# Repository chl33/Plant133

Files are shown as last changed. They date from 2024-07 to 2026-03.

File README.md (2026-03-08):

# Plant133

This is a full distribution of the Plant133 plant-watering device. This device can monitor and water up to 4 plants at a time. This repository hosts the firmware, PCBA design, and OpenSCAD code for all components.

A writeup about this project is at "[Plant1337: "Water 4 plants](https://selectiveappeal.org/posts/plant1337/)."

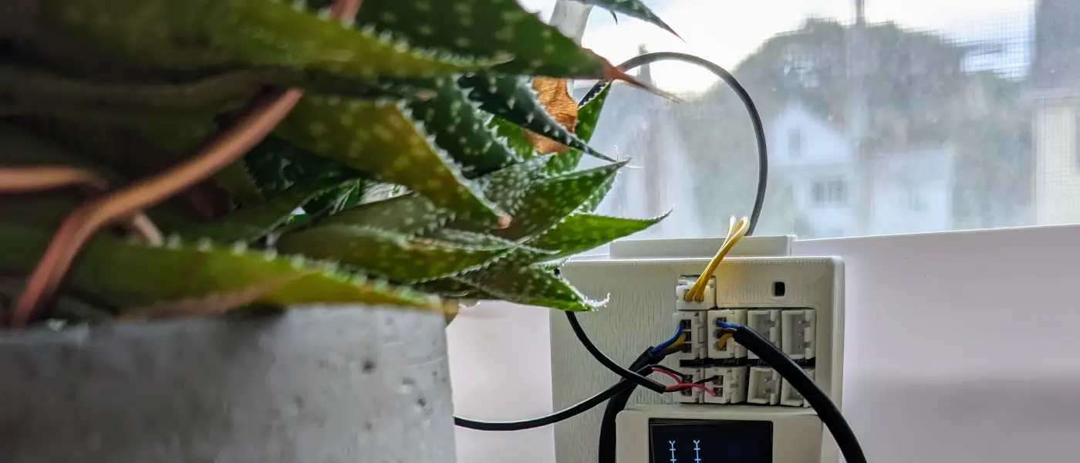
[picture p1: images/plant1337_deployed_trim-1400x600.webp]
Plant133 device


## Features

*   **Multi-Plant Support**: Monitors and independently waters up to 4 plants.
*   **Sensors**:
    *   Capacitive soil moisture sensing for each plant.
    *   SHTC3 temperature and humidity sensor for environmental monitoring.
    *   Reservoir water level float switch detection.
*   **User Interface**:
    *   **OLED Screen**: Rotates through status screens showing IP address, moisture levels, and environment data.
    *   **Web Dashboard**: A modern Svelte-based responsive web interface for real-time monitoring and configuration.
*   **Integration**:
    *   **MQTT**: Full support for Home Assistant auto-discovery and state reporting.
*   **Safety**:
    *   **Watchdog Timer**: Hardware watchdog protects against system hangs.
    *   **Dose Limiting**: Prevents over-watering by limiting the maximum number of pump cycles per day.
    *   **Reservoir Check**: Prevents pump damage by detecting low water levels.

## Usage

Please see the [instructions](instructions.md) for how to assemble and set up a Plant133 device hardware.

## Development

### Prerequisites
*   [PlatformIO](https://platformio.org/) (Core or VSCode extension)
*   [Node.js](https://nodejs.org/) (for building the web interface)

### Building and Flashing Firmware

1.  **Configure Secrets**: Copy `secrets.ini.example` to `secrets.ini` and set your WiFi credentials, OTA password, and MQTT details.
2.  **Onetime setup for building the web interface**:
    ```bash
	cd svelte
	npm install
	```
3.  **Build the Web interface and Firmware**:
    ```bash
    # For a specific board (e.g. usb_cactus)
    pio run -e usb_cactus
    ```
4.  **Upload Firmware**:
    ```bash
    pio run -e usb_cactus -t upload
    ```

## API Reference

The device exposes a JSON API for integration and control:

*   `GET /api/status`: Returns system status (temp, humidity, water level, MQTT connection).
*   `GET /api/plants`: Returns configuration for all plants.
*   `GET /api/moisture`: Returns current moisture readings and watering states.
*   `PUT /api/plants/{id}`: Update configuration for a specific plant.
*   `GET /api/wifi`: Get current WiFi SSID and board name.
*   `GET /api/mqtt`: Get MQTT configuration status.
*   `POST /test/pump`: Run a pump for a specific duration (JSON body: `{ "pumpId": 1, "duration": 1000 }`).
*   `POST /api/restart`: Restart the device.

## Software Libraries

This project is built using a custom C++ framework for ESP devices:
- [og3](https://github.com/chl33/og3): Application framework.
- [og3x-oled](https://github.com/chl33/og3x-oled): OLED screen support.
- [og3x-shtc3](https://github.com/chl33/og3x-shtc3): SHTC3 sensor support.
- [svelteesp32](https://github.com/BCsabaEngine/svelteesp32): Web interface integration.

## Hardware

### PCBA

The full [KiCAD](https://www.kicad.org/) project for the printed circuit board is in the [KiCAD](KiCAD/) subdirectory.

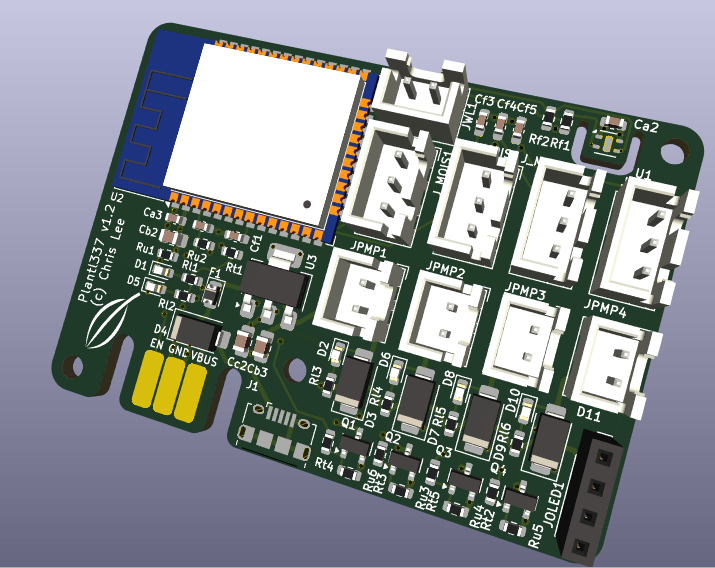
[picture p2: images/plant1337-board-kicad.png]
Plant1337 PCBA rendered by KiCAD


### 3D Printed Components

Components are designed in [OpenSCAD](https://openscad.org/). Source code is in the [scad](scad/) subdirectory.

#### Project box
Housing for the PCBA ([scad/box/](scad/box/)).
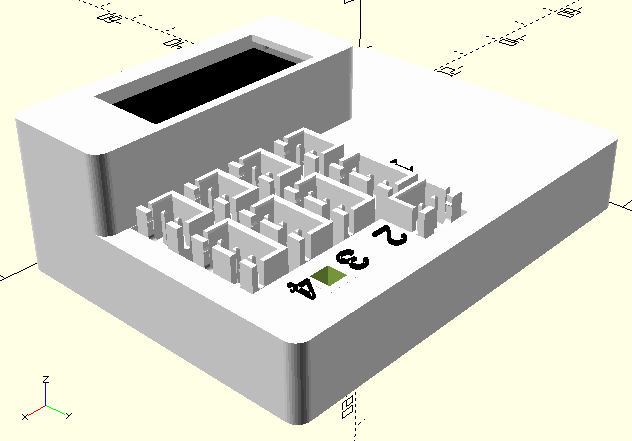
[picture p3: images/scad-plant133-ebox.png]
EBox design in OpenSCAD


#### Reservoir Hanger
Mounts the box to a water reservoir ([scad/ebox_hook](scad/ebox_hook)).
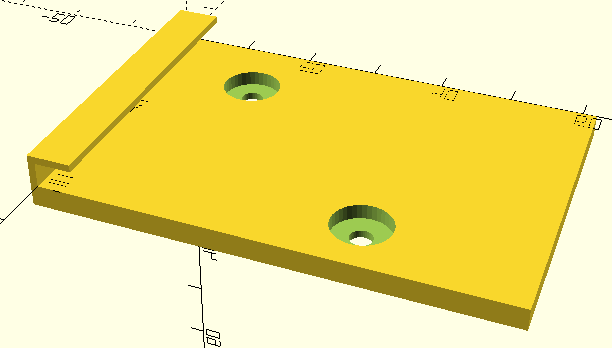
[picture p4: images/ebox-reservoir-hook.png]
Reservoir hanger


#### Reservoir Insert
Holds pumps and water level float ([scad/reservoir_insert](scad/reservoir_insert)).
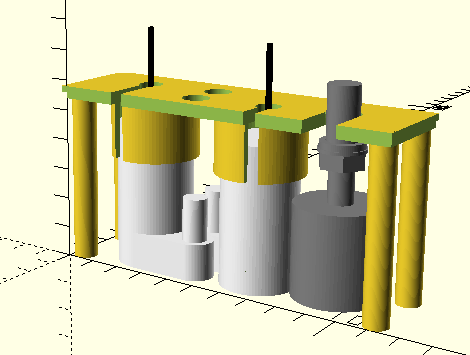
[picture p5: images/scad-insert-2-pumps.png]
Reservoir insert with 2 pumps


#### Moisture Sensor Cap
Holds the watering tube at the sensor location ([scad/moisture_sensor_cap](scad/moisture_sensor_cap)).
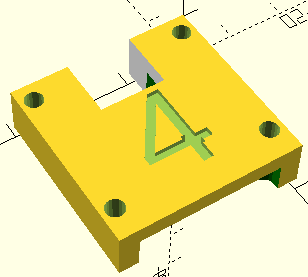
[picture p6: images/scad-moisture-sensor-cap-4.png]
Moisture sensor cap top


#### Watering Spike
Alternative watering method using a soil spike ([scad/spike](scad/spike)).
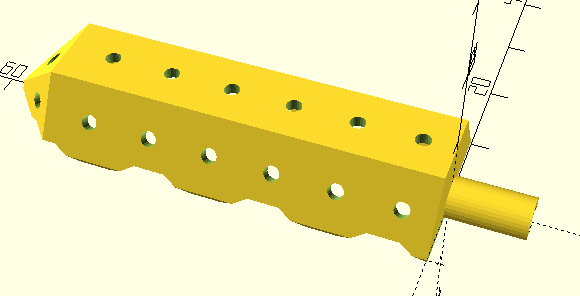
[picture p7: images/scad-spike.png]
Watering spike half


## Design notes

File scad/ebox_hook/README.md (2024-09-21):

This is a plate you can screw the EBox bottom onto, which then allows you to hang the EBox on the side of a water reservoir.

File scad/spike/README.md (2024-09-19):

This is an OpenSCAD model for a watering spike.  It is printed in 2 pieces which can be
glued together with Epoxy.

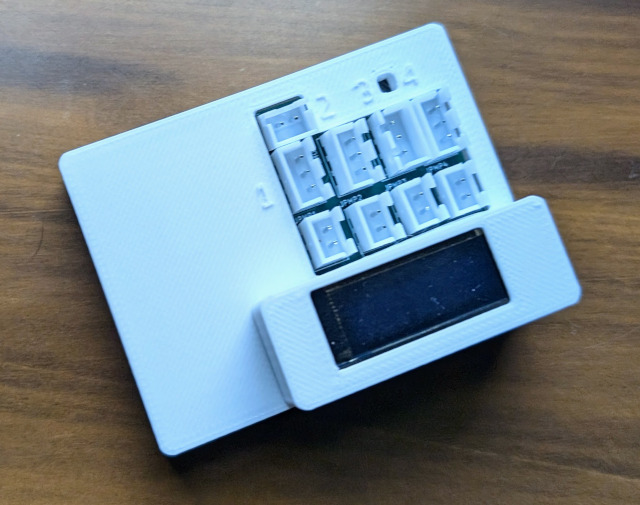
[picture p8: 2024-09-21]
images/plant1337-box.jpg

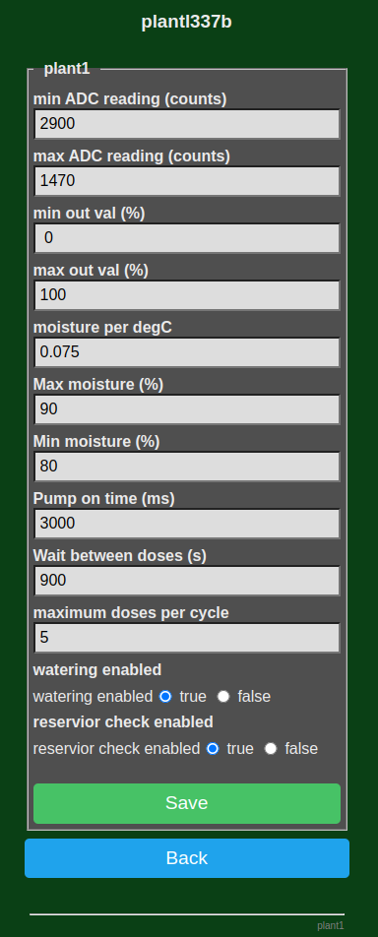
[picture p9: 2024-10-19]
images/web-water-config.png

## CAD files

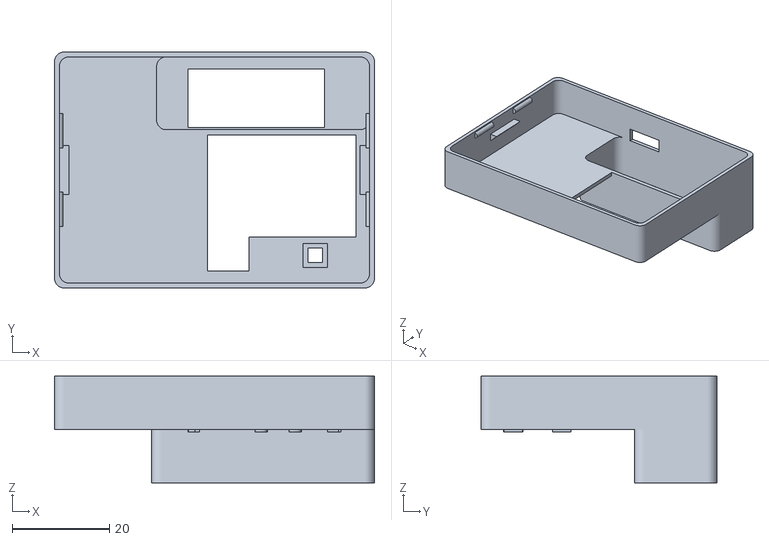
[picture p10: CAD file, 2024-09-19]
scad/box/box_top.stl
65.8 x 48.6 x 22.0

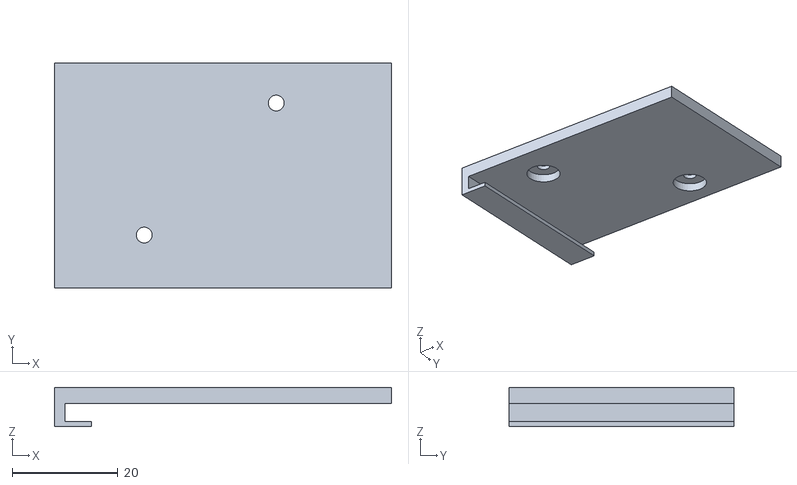
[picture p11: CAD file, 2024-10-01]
scad/ebox_hook/print_hook.stl
63.8 x 42.6 x 7.40

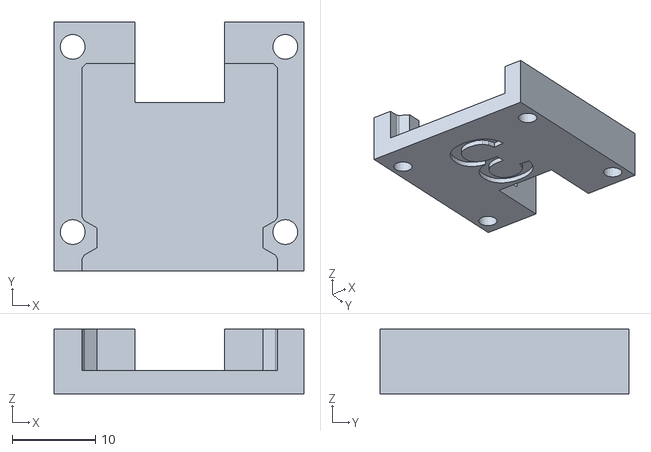
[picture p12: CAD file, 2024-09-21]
scad/moisture_sensor_cap/box_top_3.stl
30.1 x 30.0 x 7.79

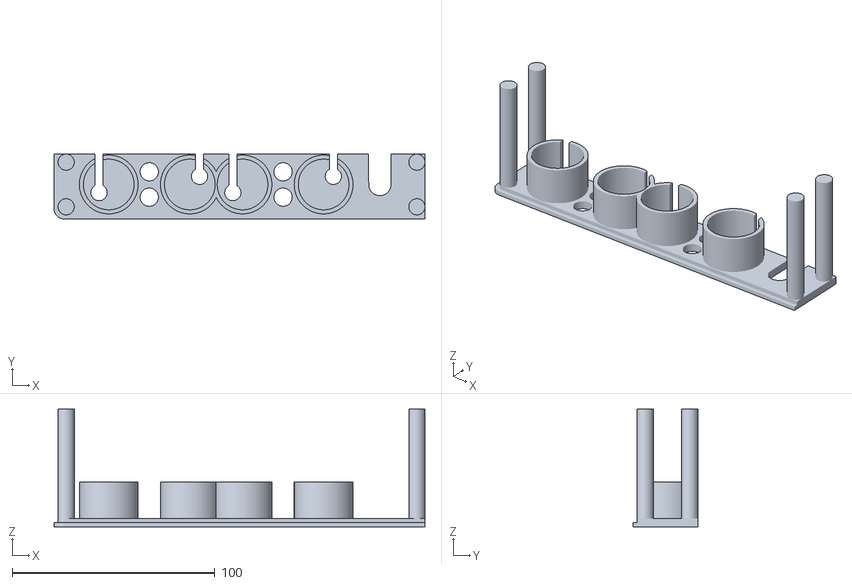
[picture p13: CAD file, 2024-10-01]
scad/reservoir_insert/insert_print.stl
183.0 x 32.0 x 58.0

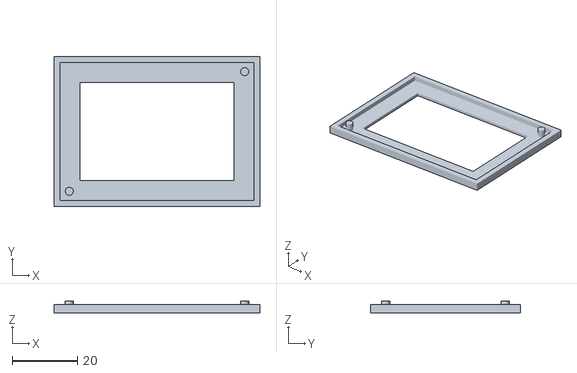
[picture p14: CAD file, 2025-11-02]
scad/stencil_fixture/stencil_fixture.stl
63.3 x 46.2 x 3.59

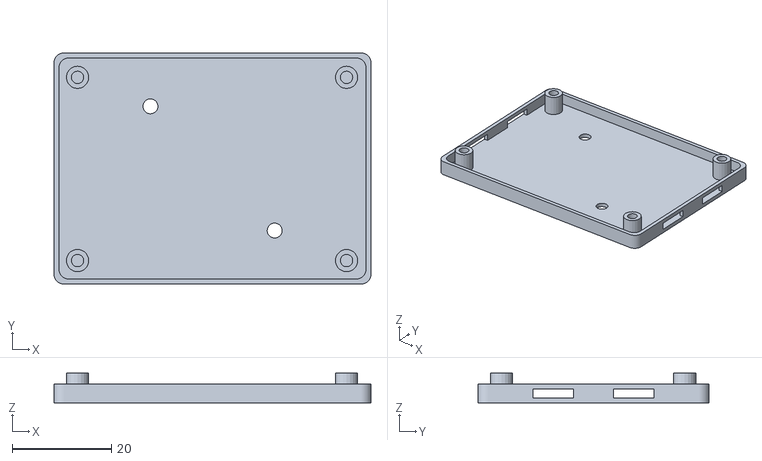
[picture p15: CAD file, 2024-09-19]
scad/box/box_bottom.stl
63.8 x 46.5 x 6.00

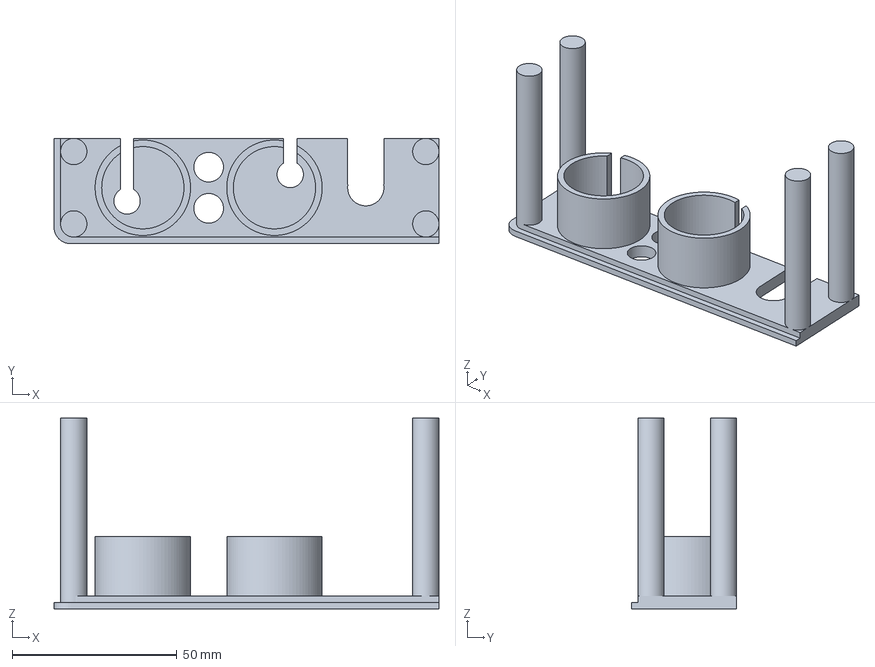
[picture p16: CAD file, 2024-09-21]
scad/reservoir_insert/reservoir_insert.3mf
117.0 x 32.0 x 58.0 mm

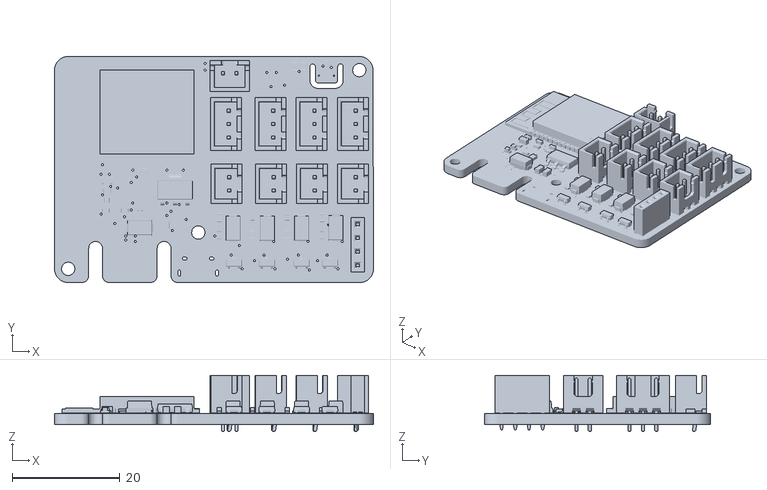
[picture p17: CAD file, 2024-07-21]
scad/box/Plant1337.stl
59.1 x 41.9 x 10.4

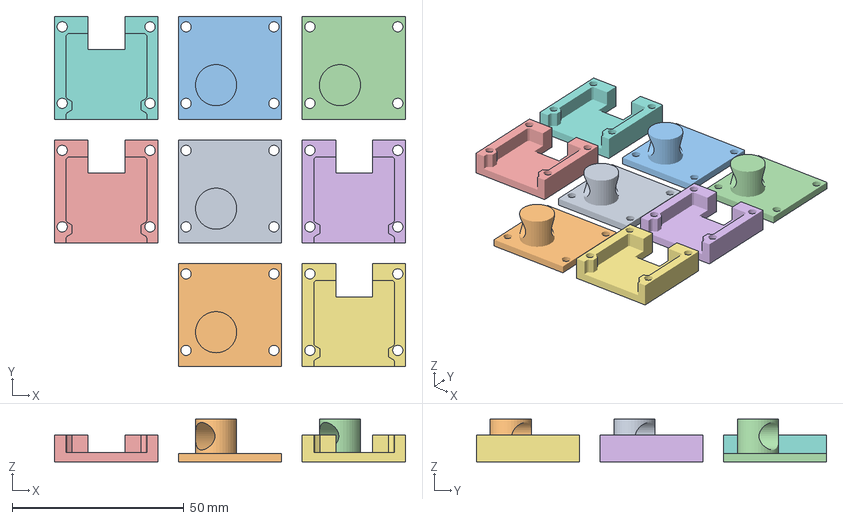
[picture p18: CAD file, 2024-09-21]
scad/moisture_sensor_cap/moisture_caps.3mf
102.3 x 102.0 x 12.5 mm
box_bottom.stl
box_top_4.stl
box_top_3.stl
box_top_2.stl
box_top_1.stl

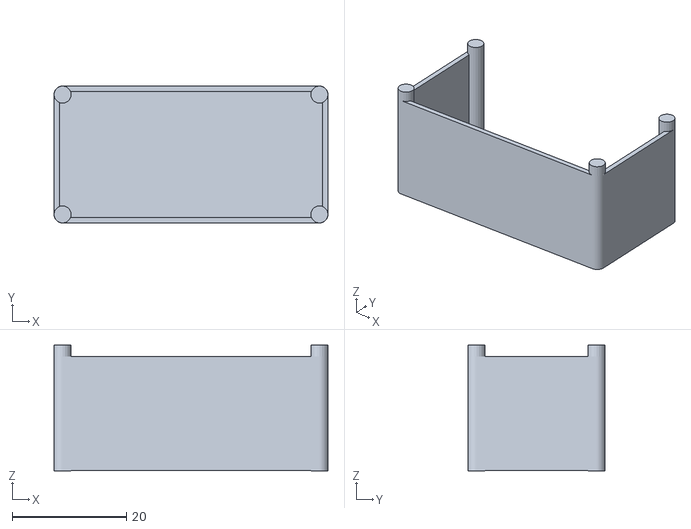
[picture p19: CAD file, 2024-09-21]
scad/reservoir_insert/insert_top_print.stl
48.0 x 24.0 x 22.0

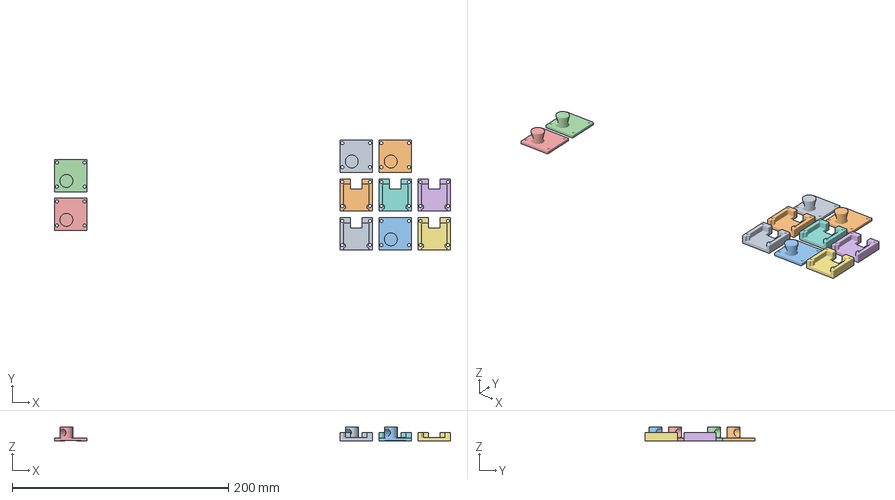
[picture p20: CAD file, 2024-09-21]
scad/moisture_sensor_cap/moisture_cap.3mf
366.2 x 102.0 x 12.5 mm
box_bottom.stl
box_top.stl

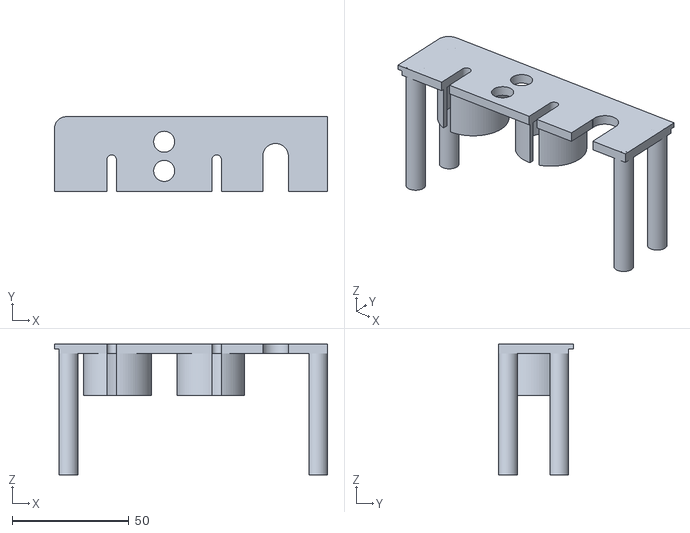
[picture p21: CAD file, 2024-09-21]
scad/reservoir_insert/insert.stl
117.0 x 32.0 x 56.0

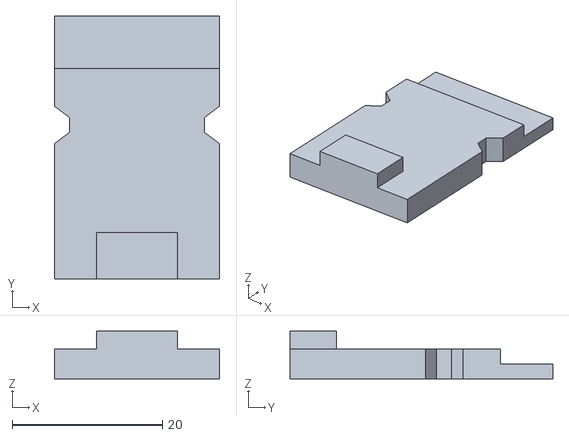
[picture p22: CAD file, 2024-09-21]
scad/moisture_sensor_cap/sensor_test.stl
22.0 x 35.0 x 6.38

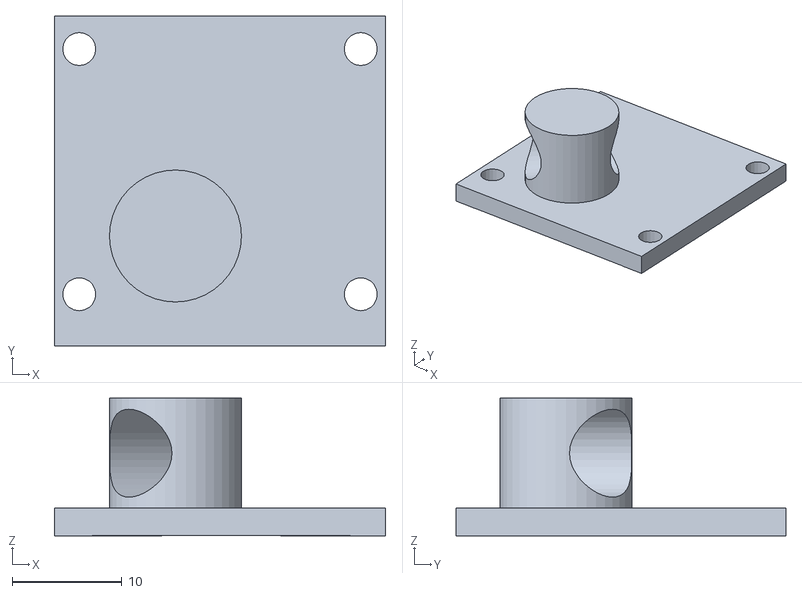
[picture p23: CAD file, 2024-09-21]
scad/moisture_sensor_cap/box_bottom.stl
30.1 x 30.0 x 12.5

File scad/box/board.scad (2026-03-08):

// Copyright (c) 2026 Chris Lee and contributors.
// Licensed under the MIT license. See LICENSE file in the project root for details.

include <ProjectBox/project_box.scad>

board_thickness = 1.6;
pad_space = 2.54;
board_dims = [23.4*pad_space, 16.6*pad_space, board_thickness];

module Plant1337_to_oled_frame() {
  u = pad_space;
  translate([u*23-0.5, 0.6, 13]) rotate([0, 0, 90]) children();
}

module oled() {
  s = inch * 0.1;
  pin_len = 4;
  color("silver") {
    for (i = [0: 3]) {
      translate([s*i+pad_space, pad_space/2, -pin_len]) cube([0.25, 0.25, pin_len]);
    }
  }
  color("gray") cube([12, 38, 1]);
  translate([0, 5.5, 1]) color("black") cube([12, 28, 1]);
}

module Plant1337_board() {
  u = pad_space;

  // Board imported from KiCad (VRML) -> meshlab
  translate([board_dims[0]/2, board_dims[1]/2, board_dims[2]/2]) color("white")
    import(file="Plant1337.stl", convexity=3);

  Plant1337_to_oled_frame() oled();
}

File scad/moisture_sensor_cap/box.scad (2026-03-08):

// Copyright (c) 2026 Chris Lee and contributors.
// Licensed under the MIT license. See LICENSE file in the project root for details.

include <moisture_sensor.scad>

sensor_num = "4";
wall_thickness = 3;

grow_offset = 0.8;

grown_moisture_sensor_dims = moisture_sensor_dims + [2, 1, 1] * grow_offset;
moisture_box_dims = [grown_moisture_sensor_dims[0] + 2 * wall_thickness,
		     30,
		     2*wall_thickness+grown_moisture_sensor_dims[2]+2];

sensor_offset = [(moisture_box_dims[0] - grown_moisture_sensor_dims[0])/2+grow_offset/2,
		 wall_thickness+2,
		 wall_thickness];

module tube_holder() {
  $fn = 40;
  difference() {
    cylinder(10, 6, 6);
    translate([0, 0, 5]) rotate(45, Z) rotate(90, X) translate([0, 0, -7]) cylinder(14, 4, 4);
  }
}

module moisure_sensor_cap(top) {
  wall = wall_thickness;
  dims = moisture_box_dims;
  difference() {
    union() {
      cube(dims);
      translate([11, 20, -10+epsilon]) tube_holder();
    }
    
    translate(sensor_offset) moisture_sensor(true);
    cut_height = 2.51;
    if (top) {
      translate([-1, -1, -20]) cube([3+dims[0], 3+dims[1], cut_height+20]);
      text_size = 15;
      text_depth = 0.8;
      translate([20.5, 25, dims[2]-text_depth+epsilon])
	linear_extrude(2*text_depth) {
	rotate(180, Z) text(sensor_num, size=text_size);
      }
    } else {
      translate([-1, -1, cut_height + epsilon]) cube([3+dims[0], 3+dims[1], 30]);
    }
    // Screw holes
    translate([0, 5.5, 0]) {
      translate([2.25, 19.8, -1]) cylinder(dims[2]+2, 3/2, 3/2, $fn=20);
      translate([dims[0]-2.25, 19.8, -1]) cylinder(dims[2]+2, 3/2, 3/2, $fn=20);
    }
    // Screw holes
    translate([0, -16.5, 0]) {
      translate([2.25, 19.5, -1]) cylinder(dims[2]+2, 3/2, 3/2, $fn=20);
      translate([dims[0]-2.25, 19.5, -1]) cylinder(dims[2]+2, 3/2, 3/2, $fn=20);
    }
  }
}

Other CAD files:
scad/moisture_sensor_cap/box_top_1.stl
scad/moisture_sensor_cap/box_top_4.stl
scad/moisture_sensor_cap/box_top_2.stl
scad/moisture_sensor_cap/box_bottom.scad
scad/moisture_sensor_cap/box_top.scad
scad/box/Plant1337_test.scad
scad/box/box.scad
scad/box/box_bottom.scad
scad/box/box_top.scad
scad/box/gui.scad
scad/ebox_hook/hook.scad
scad/ebox_hook/print_hook.scad
scad/moisture_sensor_cap/moisture_sensor.scad
scad/moisture_sensor_cap/sensor_test.scad
scad/moisture_sensor_cap/test.scad
scad/reservoir_insert/gui.scad
scad/reservoir_insert/insert_print.scad
scad/reservoir_insert/insert_test.scad
scad/reservoir_insert/insert_top_print.scad
scad/reservoir_insert/reservoir_insert.scad
scad/reservoir_insert/reservoir_insert.stl
scad/spike/spike.scad
scad/stencil_fixture/stencil_fixture.scad

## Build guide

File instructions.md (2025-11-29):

# Plant133 Setup Instructions

Follow this guide to assemble and configure your Plant133 watering system.

## 1. Hardware Assembly

### Mounting the Control Box
Hang the EBox on the side of your water reservoir. Place your plant and reservoir in their final location, ensuring access to a USB power source.

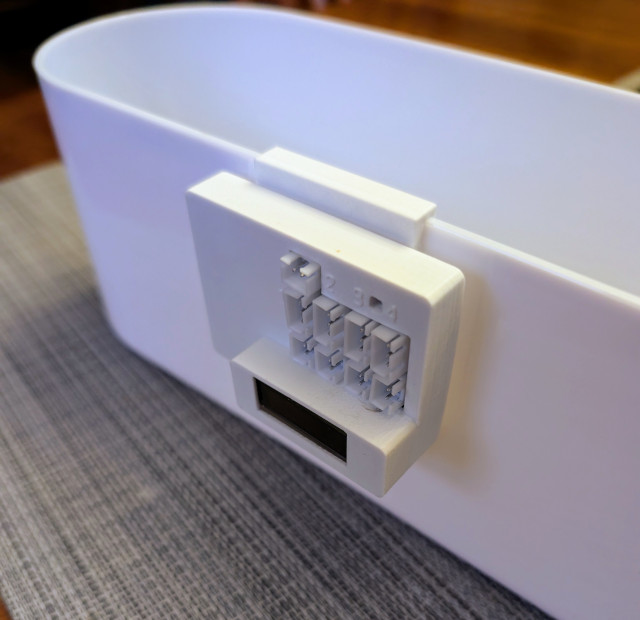
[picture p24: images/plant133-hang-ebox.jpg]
Hang EBox


### Reservoir Setup

1.  **Install the Water Level Float**:
    Place the float into the reservoir insert.
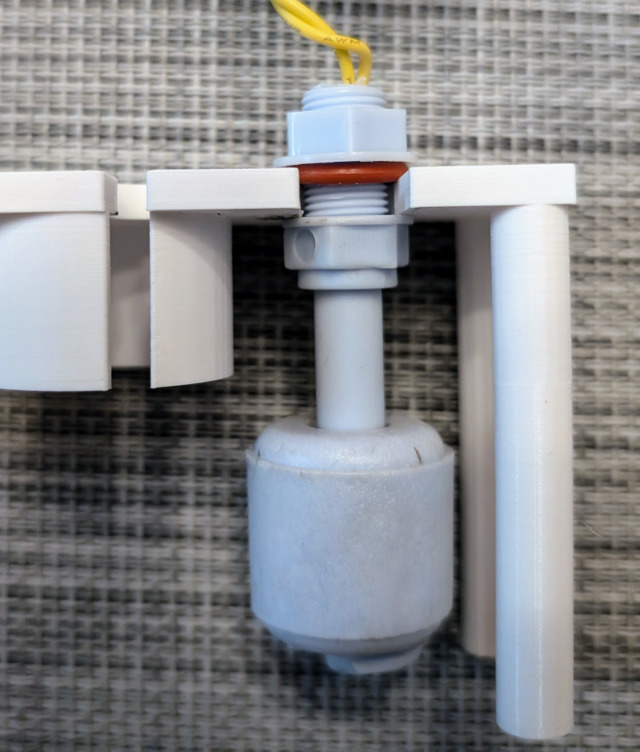
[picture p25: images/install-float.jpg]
Install Float
    

    Wire the float to the EBox.
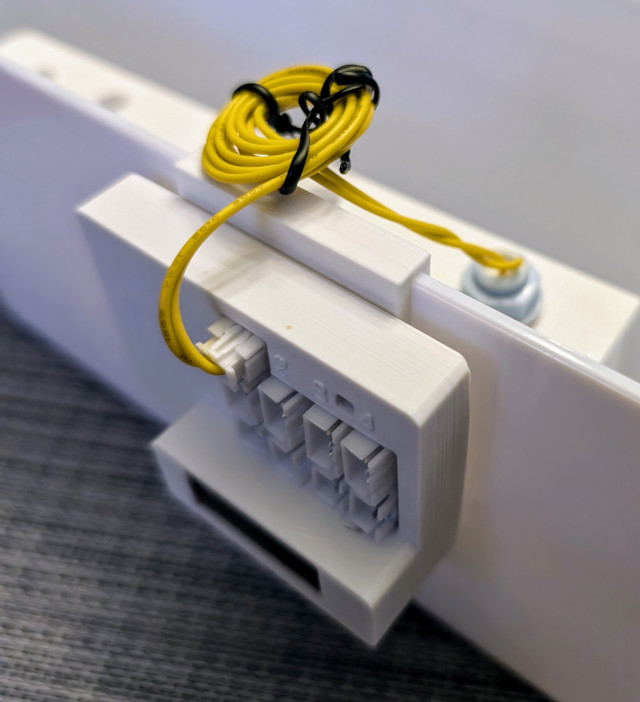
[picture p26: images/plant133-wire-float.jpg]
Wire Float
    

2.  **Install the Pump**:
    For each plant you intend to water, place a pump into the reservoir insert.
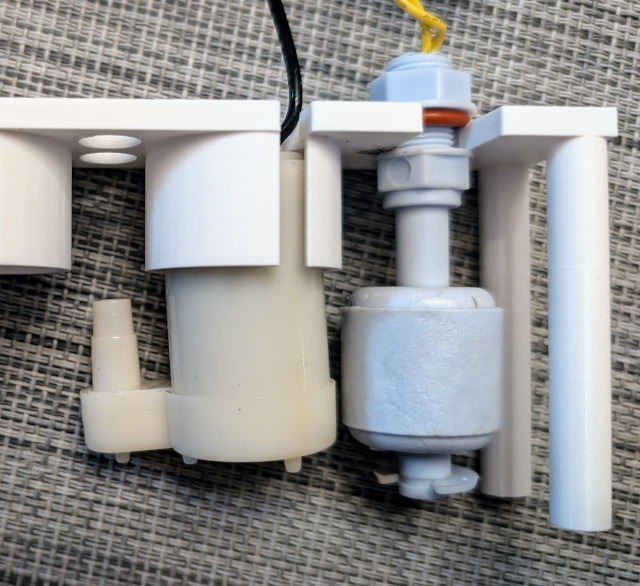
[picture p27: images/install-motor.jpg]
Install Motor
    

### Wiring and Tubing

For each plant,

3.  **Connect Sensors and Pumps**:
    Connect the soil moisture sensor and the corresponding pump to the EBox. Ensure connectors are aligned vertically under the same number (1-4).
    *   The soil moisture sensor uses a 3-conductor wire with JST connectors.
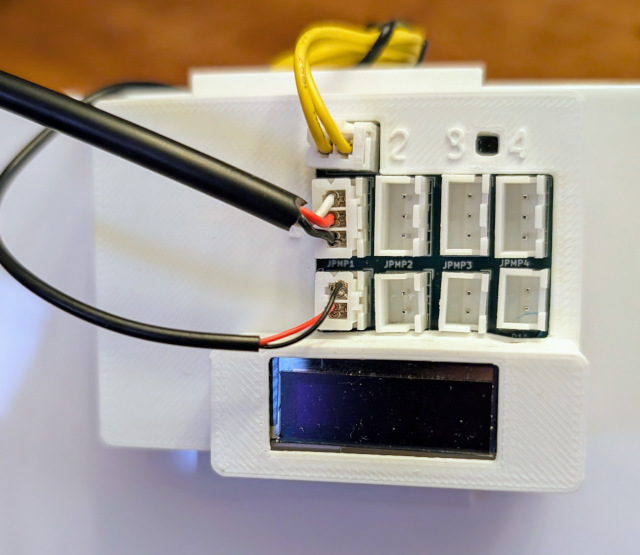
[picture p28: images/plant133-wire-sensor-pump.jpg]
Wire Sensor and Pump
    

4.  **Run Tubing**:
    Run a tube from the pump, through the hole in the insert, towards the plant pot.
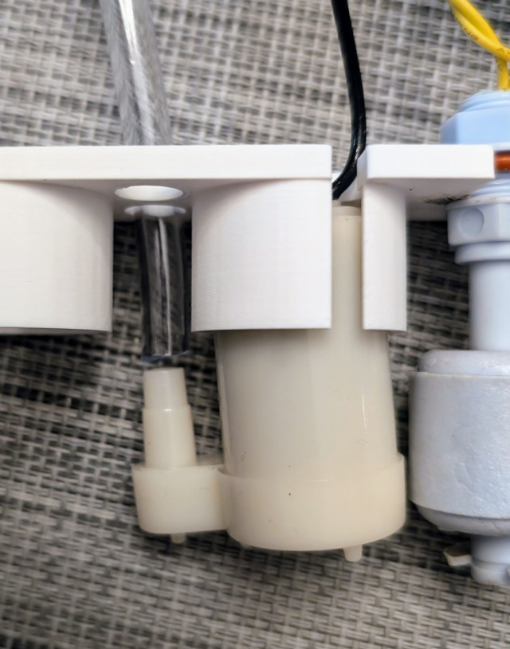
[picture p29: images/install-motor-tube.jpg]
Install Motor Tube
    

5.  **Position Water Outlet**:
    Cut the tube to the appropriate length and choose one of the following methods:
    *   **Method A (Cap)**: Push the tube end through the hole in the moisture sensor cap.
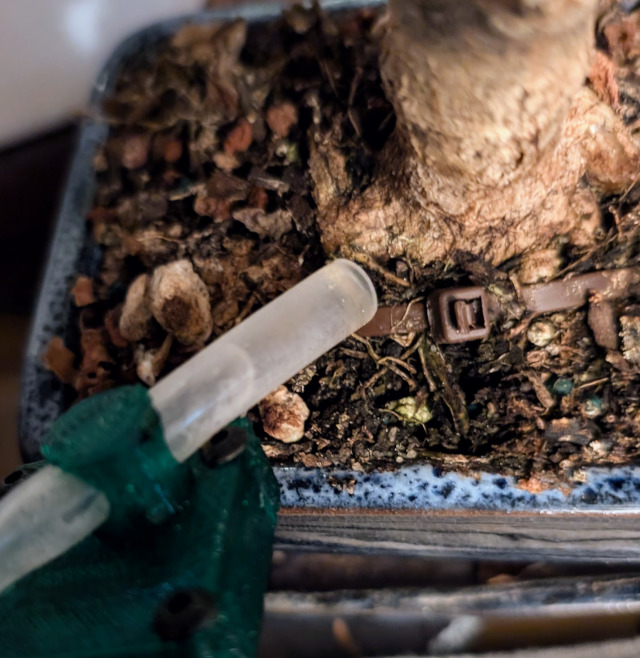
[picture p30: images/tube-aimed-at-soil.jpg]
Tube Aimed at Soil
        
    *   **Method B (Spike)**: Insert the tube into a 3D-printed soil spike and insert the spike into the soil.
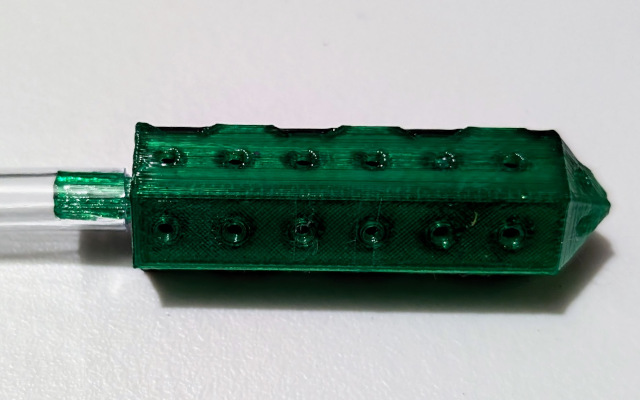
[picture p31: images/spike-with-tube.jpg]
Spike with Tube
        
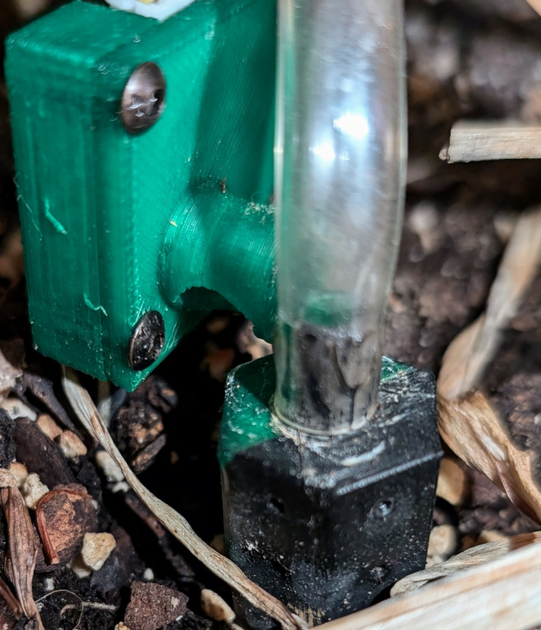
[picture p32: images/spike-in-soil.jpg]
Spike in Soil
        

6.  **Power Up**:
    Connect the EBox to power using a Micro-USB cable.

## 2. Network Configuration

1.  **Connect to Device AP**:
    Look for a WiFi network named `plant133` (or similar) on your phone or computer. Connect to it.
    *   *Note: The AP password (if set) and specific ESSID may be displayed on the device's OLED screen.*

2.  **Access Configuration Page**:
    Open a web browser and navigate to `http://192.168.4.1`. You may need to accept a warning about a non-encrypted connection.

3.  **Configure WiFi**:
    *   Click **"WiFi Setup"** on the main page.
    *   Enter your home WiFi credentials.
    *   Click **"Save"**, then **"Back"**, and finally **"Restart"** to reboot the device.
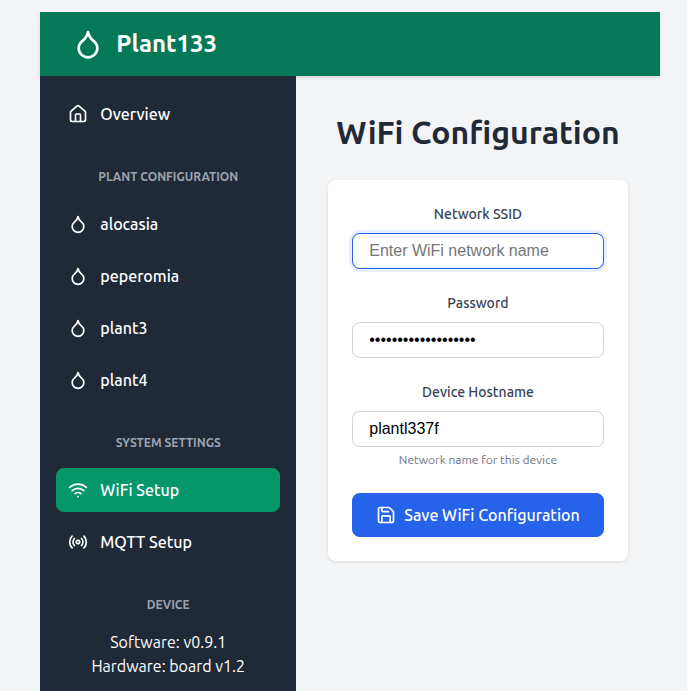
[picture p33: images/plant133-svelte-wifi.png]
Web WiFi Config
    

4.  **Reconnect**:
    Connect your phone/computer back to your home WiFi network. Look at the device's OLED screen to find its new IP address (e.g., `192.168.1.x`) or try accessing `http://plant133.local` (if mDNS is active).

## 3. Device Configuration

### MQTT Setup (Optional)
If you use Home Assistant or another home automation system:
1.  Navigate to the **MQTT Setup** page via the web interface.
2.  Enter your Broker address, port, and credentials.
3.  Save. The device should automatically appear in Home Assistant if discovery is enabled.
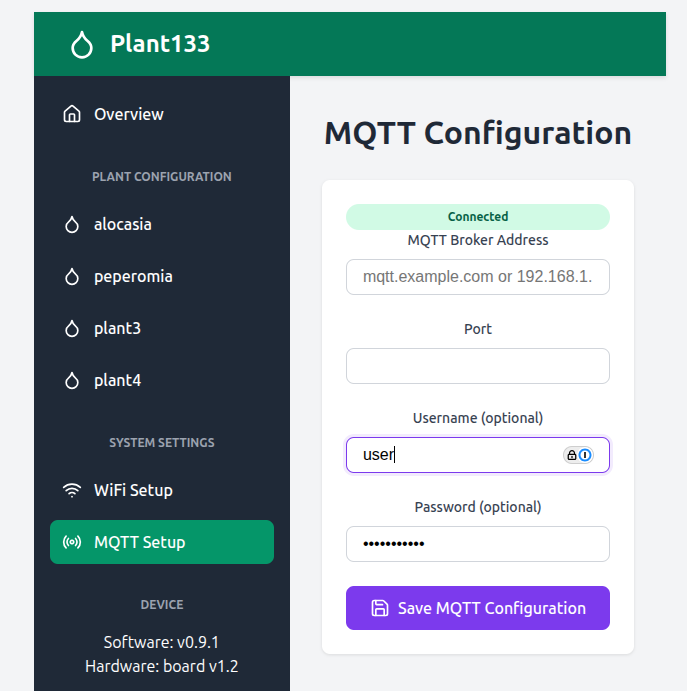
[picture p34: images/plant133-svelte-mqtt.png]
Web MQTT Config
    

### Plant Configuration
Select a plant from the main menu and click the settings icon.

*   **Moisture Targets**: Set the **Minimum** (start watering) and **Maximum** (stop watering) soil moisture percentages.
*   **Dose Duration**: Set how long the pump runs per dose (in milliseconds).
    *   *Recommendation:* Start with 1000ms (1s) for small pots, 3000ms (3s) for medium pots.
*   **Calibration**:
    *   **Wet (100%)**: Submerge the sensor (excluding the electronic cap) in a glass of water. Note the "Raw Moisture" ADC value and enter it as `ADC Counts at 100%`.
    *   **Dry (0%)**: Dry the sensor completely. Enter the reading as `ADC Counts at 0%`.
    *   *Note: Lower ADC values usually mean higher moisture (more conductivity).*
*   **Dosing Logic**:
    *   **Seconds between doses**: Time to wait for water to soak in before checking moisture again (Default: 900s / 15 min).
    *   **Max doses per cycle**: Safety limit to prevent flooding if the sensor fails (Default: 5).
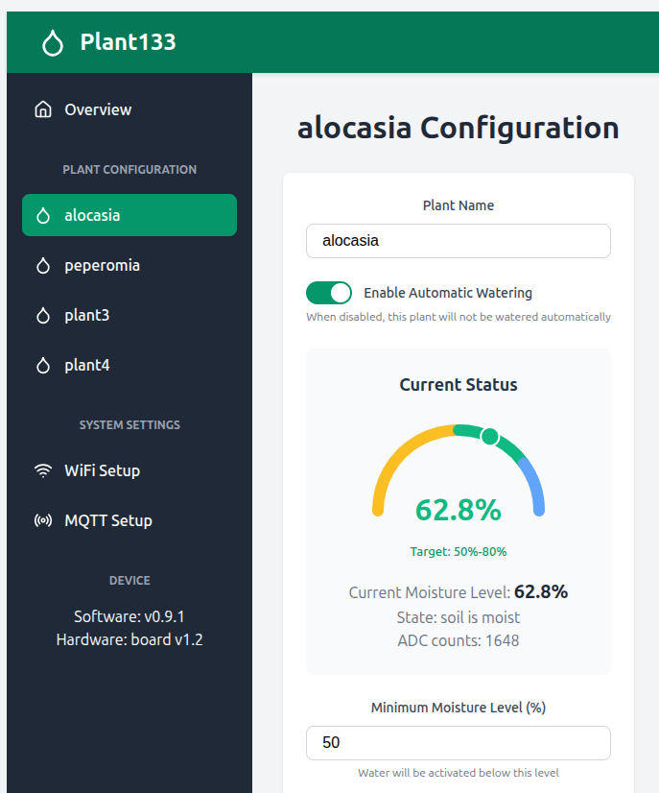
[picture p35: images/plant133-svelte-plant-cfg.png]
Web Watering Config
    

## 4. Final Steps

1.  **Enable System**: In the configuration page, toggle **"Enable Automatic Watering"**.
2.  **Fill Reservoir**: Add water to your reservoir.
3.  **Monitor**: Watch the system for the first few cycles and adjust `Pump On Time` or moisture thresholds as needed.

### Advanced
*   **Grafana**: Set up a dashboard to visualize moisture trends over time.
*   **Home Assistant**: Create automations to alert you when the reservoir is low.

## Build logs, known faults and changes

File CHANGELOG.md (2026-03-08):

# Changelog

All notable changes to this project will be documented in this file.

The format is based on [Keep a Changelog](https://keepachangelog.com/en/1.0.0/),
and this project adheres to [Semantic Versioning](https://semver.org/spec/v2.0.0.html).

## [0.9.7] - 2026-03-08

### Added
- **Web UI Enhancements**: Added real-time "Online/Offline" status indicator in the Navbar and plant-specific status dots in the sidebar.
- **Improved Sidebar**: Sidebar buttons now show MQTT connection status and visual indicators for whether a plant is enabled.
- **Centered Board Name**: Redesigned the Navbar layout to center the device board name for better aesthetics.

### Changed
- **Modernized Framework**: Upgraded to **og3 v0.5.0** and its extension libraries (**og3x-oled**, **og3x-shtc3**).
- **PsychicHttp Integration**: Switched to the modernized Request/Response networking model provided by PsychicHttp 2.1.1 on ESP32.
- **Moisture Filtering Logic**: The state machine now pauses filtered moisture updates when sensor readings are outside the calibrated calibration range.

### Fixed
- **LDF Mode**: Set `lib_ldf_mode = deep+` to ensure all transitive dependencies (e.g., Adafruit BusIO) are correctly resolved across all hardware environments.

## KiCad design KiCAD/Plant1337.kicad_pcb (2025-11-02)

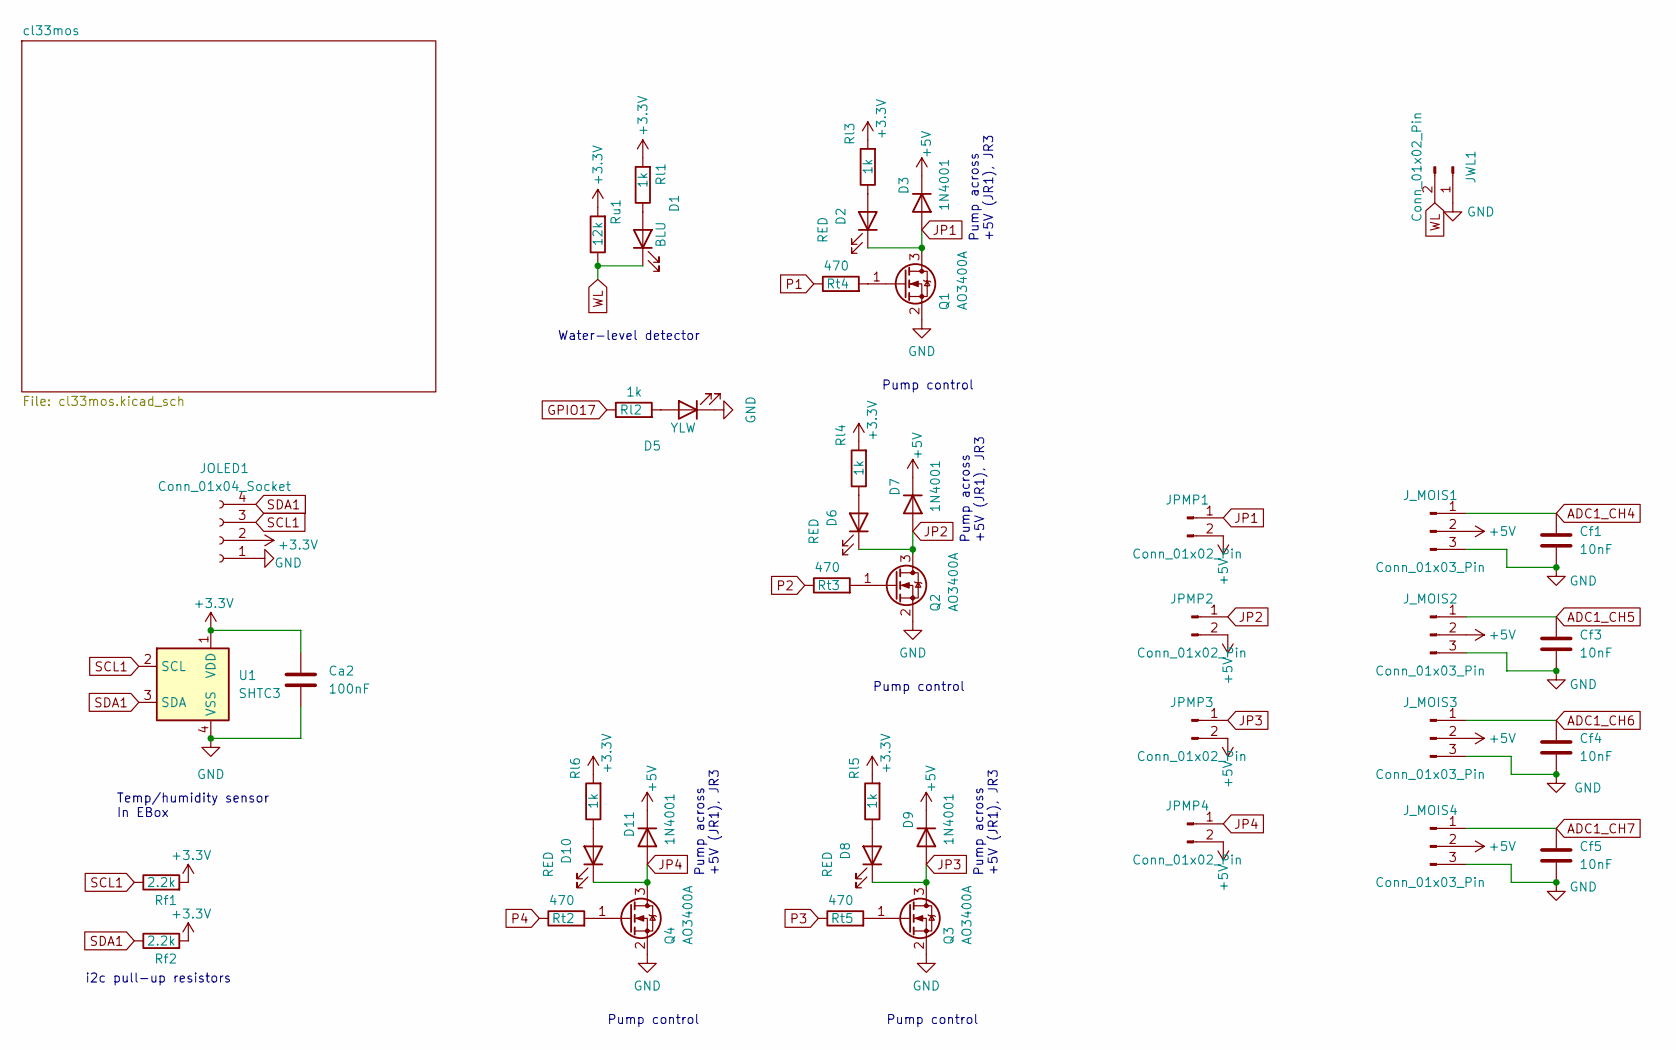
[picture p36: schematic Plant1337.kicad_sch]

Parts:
Ca2: 100nF; C_0603_1608Metric
Cf1, Cf3, Cf4, Cf5: 10nF; C_0603_1608Metric_Pad1.08x0.95mm_HandSolder
D1: BLU; LED_0603_1608Metric
D2, D6, D8, D10: RED; LED_0603_1608Metric
D3, D7, D9, D11: 1N4001; D_SMA
D5: YLW; LED_0603_1608Metric
JOLED1: Conn_01x04_Socket; PinSocket_1x04_P2.54mm_Vertical
JPMP1, JPMP2, JPMP3, JPMP4: Conn_01x02_Pin; JST_XH_B2B-XH-A_1x02_P2.50mm_Vertical
JWL1: Conn_01x02_Pin; JST_XH_B2B-XH-A_1x02_P2.50mm_Vertical
J_MOIS1, J_MOIS2, J_MOIS3, J_MOIS4: Conn_01x03_Pin; JST_XH_B3B-XH-A_1x03_P2.50mm_Vertical
Q1, Q2, Q3, Q4: AO3400A; SOT-23
Rf1, Rf2: 2.2k; R_0603_1608Metric
Rl1, Rl2, Rl3, Rl4, Rl5, Rl6: 1k; R_0603_1608Metric
Rt2, Rt3, Rt4, Rt5: 470; R_0603_1608Metric
Ru1: 12k; R_0603_1608Metric
U1: SHTC3; Sensirion_DFN-4-1EP_2x2mm_P1mm_EP0.7x1.6mm

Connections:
+3.3V: Ca2.1, JOLED1.2, Rf1.2, Rf2.2, Rl1.2, Rl3.2, Rl4.2, Rl5.2, Rl6.2, Ru1.2, U1.1 (VDD); also elsewhere on the board
+5V: D3.1 (K), D7.1 (K), D9.1 (K), D11.1 (K), JPMP1.2, JPMP2.2, JPMP3.2, JPMP4.2, J_MOIS1.2, J_MOIS2.2, J_MOIS3.2, J_MOIS4.2; also elsewhere on the board
ADC1_CH4: Cf1.2, J_MOIS1.1; also elsewhere on the board
ADC1_CH5: Cf3.2, J_MOIS2.1; also elsewhere on the board
ADC1_CH6: Cf4.2, J_MOIS3.1; also elsewhere on the board
ADC1_CH7: Cf5.2, J_MOIS4.1; also elsewhere on the board
GND: Ca2.2, Cf1.1, Cf3.1, Cf4.1, Cf5.1, D5.1 (K), JOLED1.1, JWL1.1, J_MOIS1.3, J_MOIS2.3, J_MOIS3.3, J_MOIS4.3, Q1.2 (S), Q2.2 (S), Q3.2 (S), Q4.2 (S), U1.4 (VSS); also elsewhere on the board
GPIO17: Rl2.1; also elsewhere on the board
JP1: D2.1 (K), D3.2 (A), JPMP1.1, Q1.3 (D)
JP2: D6.1 (K), D7.2 (A), JPMP2.1, Q2.3 (D)
JP3: D8.1 (K), D9.2 (A), JPMP3.1, Q3.3 (D)
JP4: D10.1 (K), D11.2 (A), JPMP4.1, Q4.3 (D)
unnamed: D1.2 (A), Rl1.1
unnamed: D2.2 (A), Rl3.1
unnamed: D5.2 (A), Rl2.2
unnamed: D6.2 (A), Rl4.1
unnamed: D8.2 (A), Rl5.1
unnamed: D10.2 (A), Rl6.1
unnamed: Q1.1 (G), Rt4.2
unnamed: Q2.1 (G), Rt3.2
unnamed: Q3.1 (G), Rt5.2
unnamed: Q4.1 (G), Rt2.2
P1: Rt4.1; also elsewhere on the board
P2: Rt3.1; also elsewhere on the board
P3: Rt5.1; also elsewhere on the board
P4: Rt2.1; also elsewhere on the board
SCL1: JOLED1.3, Rf1.1, U1.2 (SCL); also elsewhere on the board
SDA1: JOLED1.4, Rf2.1, U1.3 (SDA); also elsewhere on the board
WL: D1.1 (K), JWL1.2, Ru1.1; also elsewhere on the board

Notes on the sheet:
i2c pull-up resistors
Pump control
Pump across +5V (JR1), JR3
Water-level detector
Temp/humidity sensor In EBox

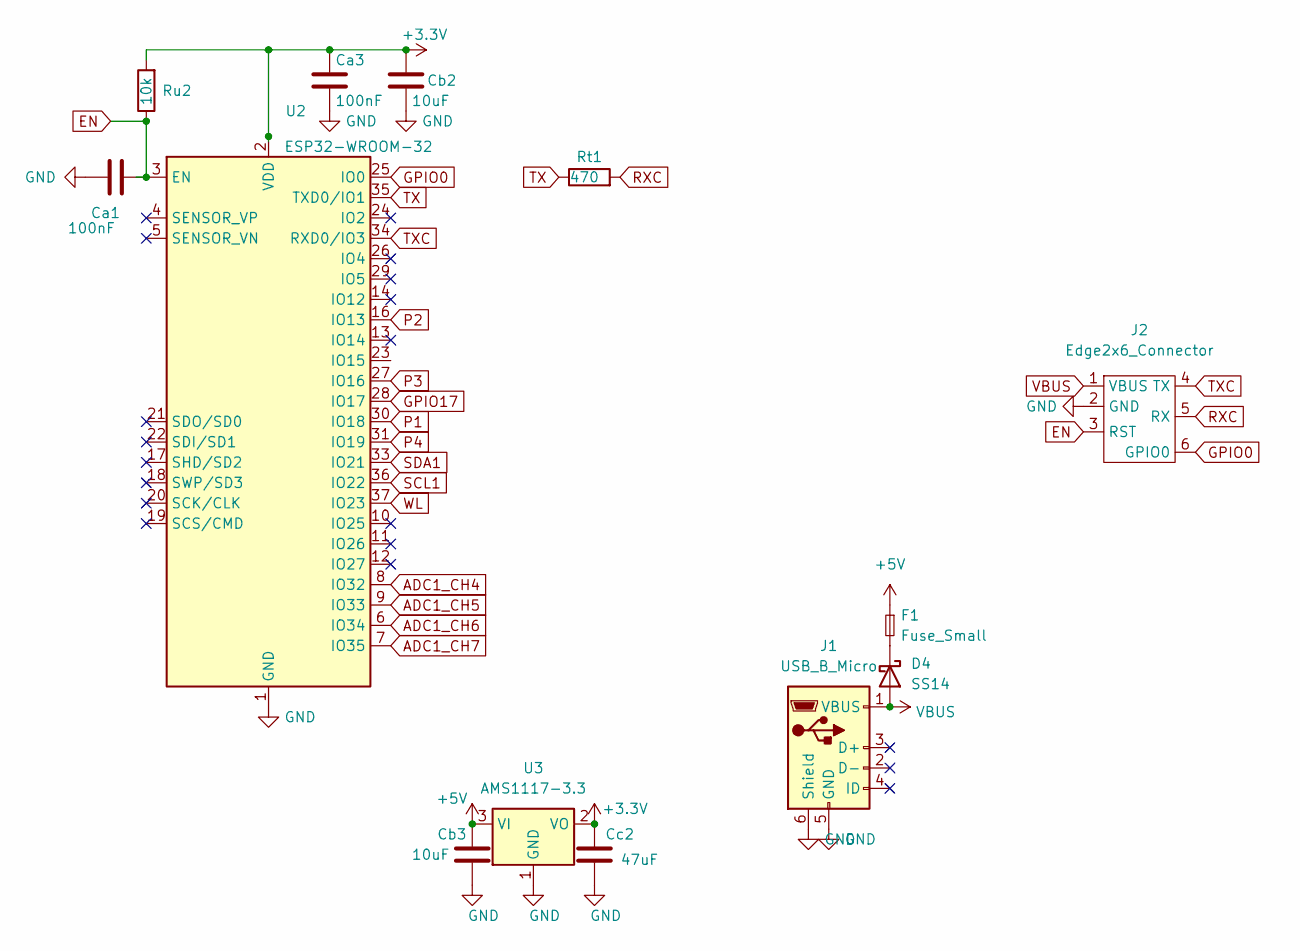
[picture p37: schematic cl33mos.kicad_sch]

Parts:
Ca1, Ca3: 100nF; C_0603_1608Metric
Cb2, Cb3: 10uF; C_0805_2012Metric_Pad1.18x1.45mm_HandSolder
Cc2: 47uF; C_0805_2012Metric_Pad1.18x1.45mm_HandSolder
D4: SS14; D_SMA
F1: Fuse_Small; D_0805_2012Metric
J1: USB_B_Micro; USB_Micro-B_Amphenol_10118194_Horizontal
J2: Edge2x6_Connector; EdgeConnector_2x3
Rt1: 470; R_0603_1608Metric
Ru2: 10k; R_0603_1608Metric
U2: ESP32-WROOM-32
U3: AMS1117-3.3; SOT-223-3_TabPin2

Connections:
+3.3V: Ca3.1, Cb2.1, Cc2.1, Ru2.2, U2.2 (VDD), U3.2 (VO); also elsewhere on the board
+5V: Cb3.1, F1.1, U3.3 (VI); also elsewhere on the board
ADC1_CH4: U2.8 (IO32); also elsewhere on the board
ADC1_CH5: U2.9 (IO33); also elsewhere on the board
ADC1_CH6: U2.6 (IO34); also elsewhere on the board
ADC1_CH7: U2.7 (IO35); also elsewhere on the board
EN: Ca1.2, J2.3 (RST), Ru2.1, U2.3 (EN)
GND: Ca1.1, Ca3.2, Cb2.2, Cb3.2, Cc2.2, J1.5 (GND), J1.6 (Shield), J2.2 (GND), U2.1 (GND), U2.15 (GND), U2.38 (GND), U2.39 (GND), U3.1 (GND); also elsewhere on the board
GPIO0: J2.6 (GPIO0), U2.25 (IO0)
GPIO17: U2.28 (IO17); also elsewhere on the board
unnamed: D4.1 (K), F1.2
P1: U2.30 (IO18); also elsewhere on the board
P2: U2.16 (IO13); also elsewhere on the board
P3: U2.27 (IO16); also elsewhere on the board
P4: U2.31 (IO19); also elsewhere on the board
RXC: J2.5 (RX), Rt1.2
SCL1: U2.36 (IO22); also elsewhere on the board
SDA1: U2.33 (IO21); also elsewhere on the board
TX: Rt1.1, U2.35 (TXD0/IO1)
TXC: J2.4 (TX), U2.34 (RXD0/IO3)
VBUS: D4.2 (A), J1.1 (VBUS), J2.1 (VBUS)
WL: U2.37 (IO23); also elsewhere on the board

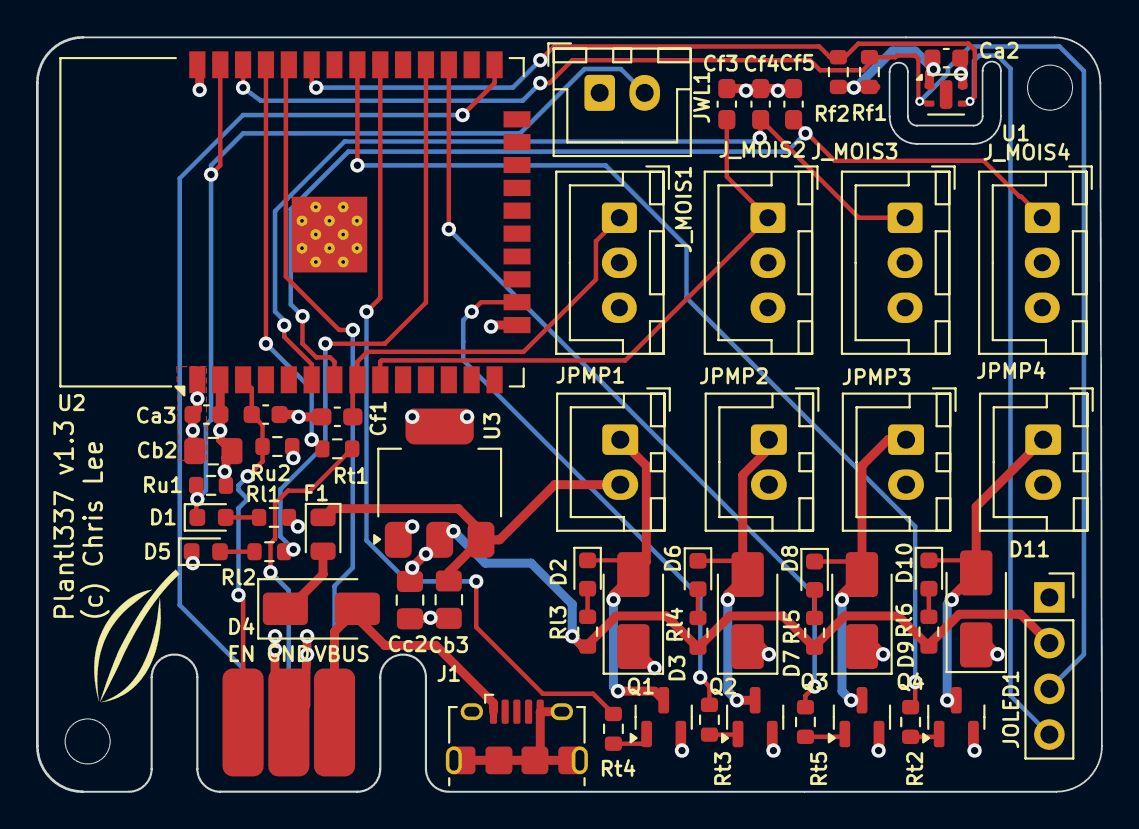
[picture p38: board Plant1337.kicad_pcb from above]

Board: 4 copper layers, 59.1 x 41.9 mm, 56 parts (0 on the bottom side), 36 nets.

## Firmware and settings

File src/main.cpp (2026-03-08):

// Copyright (c) 2026 Chris Lee and contributors.
// Licensed under the MIT license. See LICENSE file in the project root for details.

#include <Arduino.h>
#include <ArduinoOTA.h>
#include <LittleFS.h>
#include <og3/constants.h>
#include <og3/ha_app.h>
#include <og3/html_table.h>
#include <og3/oled_wifi_info.h>
#include <og3/shtc3.h>
#include <og3/units.h>
#include <og3/variable.h>
#include <og3/wifi_watchdog.h>

#include <algorithm>
#include <array>

#include "svelteesp32async.h"
#include "watering.h"

#define SW_VERSION "0.9.7"

namespace {

const char kManufacturer[] = "Chris Lee";
const char kModel[] = "Plantl337";
const char kSoftware[] = "PlantL33 " SW_VERSION;

// -- Hardware configuration,
constexpr uint8_t kWaterPin = 23;
constexpr uint8_t kModeLED = 17;

// Soil moisure sensor ADC pin assignments.
// - gpio32: adc1_ch4 -> mois1
// - gpio33: adc1_ch5 -> mois2
// - gpio34: adc1_ch6 -> mois3
// - gpio35: adc1_ch7 -> mois4
constexpr uint8_t kMoistureAnalogPin[4] = {32, 33, 34, 35};
#if BOARD_V13
// The pins on the v1.3 board. Changed pump-2 pin to not be on when power is first applied.
constexpr uint8_t kPumpCtlPin[4] = {18, 13, 16, 19};
#else
// The pins on the v1.2 board.
constexpr uint8_t kPumpCtlPin[4] = {18, 5, 16, 19};
#endif
constexpr unsigned kOledSwitchMsec = 5000;

#if defined(LOG_UDP) && defined(LOG_UDP_ADDRESS)
constexpr og3::App::LogType kLogType = og3::App::LogType::kUdp;
#else
constexpr og3::App::LogType kLogType = og3::App::LogType::kSerial;  // kSerial
#endif

// og3 application definition
og3::HAApp s_app(og3::HAApp::Options(
    kManufacturer, kModel,
    og3::WifiApp::Options()
        .withSoftwareName(kSoftware)
        .withDefaultDeviceName("plant133")
        .withOta(og3::OtaManager::Options(OTA_PASSWORD))
#if defined(AP_PASSWORD)
        .withWifi(og3::WifiManager::Options().withApPassword(AP_PASSWORD))
#endif
#if defined(LOG_UDP) && defined(LOG_UDP_ADDRESS)
        .withUdpLogHost(IPAddress(LOG_UDP_ADDRESS))
#endif
        .withApp(og3::App::Options().withLogType(kLogType).withReserveTasks(32))));

// Have oled display IP address or AP status.
og3::OledWifiInfo wifi_infof(&s_app.tasks());
// Have OLED screen rotate between different views over time.
og3::OledDisplayRing s_oled(&s_app.module_system(), kModel, kOledSwitchMsec, og3::Oled::kSixteenPt,
                            og3::Oled::Orientation::kDefault);

// Temperature/humidity sensing in the vicinity of the device.
og3::VariableGroup s_climate_vg("plant133");
og3::Shtc3 s_shtc3("temperature", "humidity", &s_app.module_system(), "temperature", s_climate_vg);

// A periodic task to monitor temperature/humidity and send the results via MQTT.
og3::PeriodicTaskScheduler climate_scheduler(
    10 * og3::kMsecInSec, og3::kMsecInMin,
    []() {
      s_shtc3.read();
      s_app.mqttSend(s_climate_vg);
    },
    &s_app.tasks());

og3::WifiWatchdog s_watchdog(&s_app, std::chrono::seconds(5), std::chrono::seconds(1));

// s_reservior monitors the water level of the reservoir: the float, and the number of seconds
//  the pumps have run since the float detected low water level.
og3::ReservoirCheck s_reservoir(kWaterPin, &s_app);

// s_plants are the 4 different plant watering sytems.
// The code for the plant watering system is in lib/watering/.
std::array<og3::Watering, 4> s_plants{{
    {0, "plant1", kMoistureAnalogPin[0], kModeLED, kPumpCtlPin[0], &s_app},
    {1, "plant2", kMoistureAnalogPin[1], kModeLED, kPumpCtlPin[1], &s_app},
    {2, "plant3", kMoistureAnalogPin[2], kModeLED, kPumpCtlPin[2], &s_app},
    {3, "plant4", kMoistureAnalogPin[3], kModeLED, kPumpCtlPin[3], &s_app},
}};

// Web interface buttons for the main device web page.
og3::WebButton s_button_wifi_config = s_app.createWifiConfigButton();
og3::WebButton s_button_mqtt_config = s_app.createMqttConfigButton();
og3::WebButton s_button_app_status = s_app.createAppStatusButton();
og3::WebButton s_button_restart = s_app.createRestartButton();

static String s_body;

// Web callback for main device web page.
og3::NetHandlerStatus handleWebRoot(og3::NetRequest* request, og3::NetResponse* response) {
  s_body.clear();
  s_shtc3.read();
  og3::html::writeTableInto(&s_body, s_climate_vg);
  // Write a table of watering state variables.
  og3::html::writeTableInto(&s_body, s_reservoir.variables());
  // Write state of Wifi
  og3::html::writeTableInto(&s_body, s_app.wifi_manager().variables());
  // Write state of MQTT
  og3::html::writeTableInto(&s_body, s_app.mqtt_manager().variables());
  // Add config for reservoir.
  s_reservoir.add_html_status_button(&s_body);
  // Add a button for watering status for each system
  for (const auto& plant : s_plants) {
    plant.add_html_status_button(&s_body);
  }
  // Add a button for configuring Wifi.
  s_button_wifi_config.add_button(&s_body);
  // Add a button for configuring MQTT.
  s_button_mqtt_config.add_button(&s_body);
  // Add a button for looking at app state.
  s_button_app_status.add_button(&s_body);

  s_body +=
      ("<p><button onclick=\"location.href='/static/test.html'\" type=\"button\">"
       "Test</button></p>\n");

  // Add a button for rebooting the device.
  s_button_restart.add_button(&s_body);
  // Send the page back to the web client.
  og3::sendWrappedHTML(request, response, s_app.board_cname(), kSoftware, s_body.c_str());
  NET_REPLY(request, ESP_OK);
}

void draw_graphs() {
  constexpr int16_t kScreenWidth = 128;
  constexpr int16_t kScreenHeight = 32;
  constexpr int16_t kMargin = 3;
  constexpr int kYScreenTop = kMargin;
  constexpr int kYScreenBot = kScreenHeight - kMargin;

  s_oled.clear();
  auto& scr = s_oled.screen();
  for (size_t i = 0; i < s_plants.size(); i++) {
    const auto& plant = s_plants[i];
    if (!plant.isEnabled()) {
      continue;
    }

    struct PercentToY {
      float m_slope, m_pmin;
      PercentToY(float min, float max) {
        const float mid = (min + max) / 2.0f;
        const float diff = max - min;
        const float pmax = std::min(100.0f, mid + diff);
        m_pmin = std::max(0.0f, mid - diff);
        m_slope = static_cast<float>(kYScreenTop - kYScreenBot) / (pmax - m_pmin);
      }
      int16_t y(float percent) const {
        const int16_t out = static_cast<int16_t>((percent - m_pmin) * m_slope) + kYScreenBot;
        return (out < kYScreenTop) ? kYScreenTop : (out > kYScreenBot) ? kYScreenBot : out;
      }
    } p2y(plant.minTarget(), plant.maxTarget());

    auto line = [&scr, &p2y](int16_t x, float percent, int16_t offset) {
      const int16_t y1 = p2y.y(percent);
      const int16_t y2 = y1 + offset;
      scr.drawLine(x - 3, y2, x, y1);
      scr.drawLine(x, y1, x + 3, y2);
    };

    const int16_t x = kScreenWidth * (1 + 2 * i) / 8;
    scr.drawVerticalLine(x, kMargin, kScreenHeight - (2 * kMargin));
    line(x, plant.minTarget(), 0);
    line(x, plant.maxTarget(), 0);
    line(x, plant.moisturePercent(), 3 * plant.direction());
  }
  s_oled.screen().display();
}

og3::NetHandlerStatus statusJson(og3::NetRequest* request, og3::NetResponse* response) {
  s_body.clear();
  s_shtc3.read();
  JsonDocument jsondoc;
  JsonObject json = jsondoc.to<JsonObject>();
  s_climate_vg.toJson(json, 0);
  s_reservoir.variables().toJson(json, 0);
  for (const auto& plant : s_plants) {
    plant.variables().toJson(json, 0);
  }
  serializeJson(jsondoc, s_body);
  response->send(200, "application/json", s_body.c_str());
  NET_REPLY(request, ESP_OK);
}

og3::NetHandlerStatus apiGetPlants(og3::NetRequest* request, og3::NetResponse* response) {
  JsonDocument jsondoc;
  JsonArray array = jsondoc.to<JsonArray>();
  int id = 0;
  for (const auto& plant : s_plants) {
    JsonObject json = array.add<JsonObject>();
    id += 1;
    json["id"] = id;
    plant.getApiPlants(json);
  }
  serializeJson(jsondoc, s_body);
  response->send(200, "application/json", s_body.c_str());
  NET_REPLY(request, ESP_OK);
}

og3::NetHandlerStatus apiGetMoisture(og3::NetRequest* request, og3::NetResponse* response) {
  JsonDocument jsondoc;
  JsonArray array = jsondoc.to<JsonArray>();
  int id = 0;
  for (const auto& plant : s_plants) {
    JsonObject json = array.add<JsonObject>();
    id += 1;
    json["id"] = id;
    json["moisture"] = plant.moisturePercent();
    json["rawMoisture"] = plant.rawMoisture();
    json["doseCount"] = plant.doseLog().doseCount();
    json["state"] = plant.stateName();
  }
  serializeJson(jsondoc, s_body);
  response->send(200, "application/json", s_body.c_str());
  NET_REPLY(request, ESP_OK);
}

og3::NetHandlerStatus apiGetStatus(og3::NetRequest* request, og3::NetResponse* response) {
  JsonDocument jsondoc;
  JsonObject json = jsondoc.to<JsonObject>();
  json["temperature"] = s_shtc3.temperature();
  json["humidity"] = s_shtc3.humidity();
  json["waterLevel"] = s_reservoir.haveWater();
  json["pumpTimeRemaining"] = s_reservoir.secondsRemaining();
  json["mqttConnected"] = s_app.mqtt_manager().isConnected();
  json["software"] = SW_VERSION;
#if BOARD_V13
  json["hardware"] = "1.3";
#else
  json["hardware"] = "1.2";
#endif
  serializeJson(jsondoc, s_body);
  response->send(200, "application/json", s_body.c_str());
  NET_REPLY(request, ESP_OK);
}

og3::NetHandlerStatus putApiPlant(int id, og3::NetRequest* request, og3::NetResponse* response,
                                  JsonVariant& jsonIn) {
  if (id < 1 || id > static_cast<int>(s_plants.size())) {
    response->send(500, "text/plain", "bad plant id");
    NET_REPLY(request, ESP_FAIL);
  }
  if (!jsonIn.is<JsonObject>()) {
    response->send(500, "text/plain", "not a json object");
    NET_REPLY(request, ESP_FAIL);
  }
  JsonObject obj = jsonIn.as<JsonObject>();
  if (!s_plants[id - 1].putApiPlants(obj)) {
    response->send(500, "text/plain", "failed to update plant");
    NET_REPLY(request, ESP_FAIL);
  }
  response->send(200, "text/plain", "ok");
  NET_REPLY(request, ESP_OK);
}

og3::NetHandlerStatus pumpTest(og3::NetRequest* request, og3::NetResponse* response,
                               JsonVariant& jsonIn) {
  if (!jsonIn.is<JsonObject>()) {
    response->send(200, "application/json", "{\"isOk\":false,\"message\":\"Not an object\"}");
    NET_REPLY(request, ESP_FAIL);
  }
  const JsonObject jsonObj = jsonIn.as<JsonObject>();
  const int pump_id = jsonObj["pumpId"].as<int>();
  const int duration = jsonObj["duration"].as<int>();
  if (pump_id >= 1 && pump_id <= 4 && duration >= 0) {
    s_plants[pump_id - 1].relay().turnOn(duration);
    response->send(200, "application/json", "{\"isOk\":true}");
    NET_REPLY(request, ESP_OK);
  }
  response->send(200, "application/json", "{\"isOk\":false,\"message\":\"Bad values\"}");
  NET_REPLY(request, ESP_FAIL);
}

og3::NetHandlerStatus configJson(og3::NetRequest* request, og3::NetResponse* response) {
  s_body.clear();
  JsonDocument jsondoc;
  JsonObject json = jsondoc.to<JsonObject>();
  s_reservoir.configVariables().toJson(json, og3::VariableBase::Flags::kConfig);
  for (const auto& plant : s_plants) {
    plant.configVariables().toJson(json, og3::VariableBase::Flags::kConfig);
  }
  serializeJson(jsondoc, s_body);
  response->send(200, "application/json", s_body.c_str());
  NET_REPLY(request, ESP_OK);
}

og3::NetHandlerStatus apiGetWifi(og3::NetRequest* request, og3::NetResponse* response) {
  JsonDocument jsondoc;
  JsonObject json = jsondoc.to<JsonObject>();
  const auto& wifi = s_app.wifi_manager();
  json["board"] = wifi.board();
  json["password"] = wifi.password();
  json["essid"] = wifi.essid();
  serializeJson(jsondoc, s_body);
  response->send(200, "application/json", s_body.c_str());
  NET_REPLY(request, ESP_OK);
}

og3::NetHandlerStatus putWifiConfig(og3::NetRequest* request, og3::NetResponse* response,
                                    JsonVariant& jsonIn) {
  if (!jsonIn.is<JsonObject>()) {
    response->send(500, "text/plain", "not a json object");
    NET_REPLY(request, ESP_FAIL);
  }
  JsonObject obj = jsonIn.as<JsonObject>();
  s_app.wifi_manager().variables().updateFromJson(obj);
  s_app.config().write_config(s_app.wifi_manager().variables());
  response->send(200, "text/plain", "ok");
  NET_REPLY(request, ESP_OK);
}

og3::NetHandlerStatus apiGetMqtt(og3::NetRequest* request, og3::NetResponse* response) {
  JsonDocument jsondoc;
  JsonObject json = jsondoc.to<JsonObject>();
  const auto& mqtt = s_app.mqtt_manager();
  json["enabled"] = mqtt.isEnabled();
  json["host"] = mqtt.host();
  json["password"] = mqtt.auth_password();
  json["user"] = mqtt.auth_user();
  serializeJson(jsondoc, s_body);
  response->send(200, "application/json", s_body.c_str());
  NET_REPLY(request, ESP_OK);
}

og3::NetHandlerStatus putMqttConfig(og3::NetRequest* request, og3::NetResponse* response,
                                    JsonVariant& jsonIn) {
  if (!jsonIn.is<JsonObject>()) {
    response->send(500, "text/plain", "not a json object");
    NET_REPLY(request, ESP_FAIL);
  }
  JsonObject obj = jsonIn.as<JsonObject>();
  s_app.mqtt_manager().variables().updateFromJson(obj);
  s_app.config().write_config(s_app.mqtt_manager().variables());
  if (s_app.mqtt_manager().isEnabled() && !s_app.mqtt_manager().isConnected()) {
    s_app.mqtt_manager().connect();
  } else if (!s_app.mqtt_manager().isEnabled() && s_app.mqtt_manager().isConnected()) {
    s_app.mqtt_manager().disconnect();
  }
  response->send(200, "text/plain", "ok");
  NET_REPLY(request, ESP_OK);
}

}  // namespace

void setup() {
  s_oled.addDisplayFn(draw_graphs);
  s_app.web_server_module().native_server().serveStatic("/config/", LittleFS, "/");
  s_app.web_server_module().on("/test/status", statusJson);
  s_app.web_server_module().on("/test/config", configJson);
  s_app.web_server_module().on("/root", handleWebRoot);

  initSvelteStaticFiles(&s_app.web_server_module().native_server());
  s_app.web_server_module().on("/api/plants", HTTP_GET, apiGetPlants);
  s_app.web_server_module().on("/api/wifi", HTTP_GET, apiGetWifi);
  s_app.web_server_module().on("/api/mqtt", HTTP_GET, apiGetMqtt);
  s_app.web_server_module().on("/api/moisture", HTTP_GET, apiGetMoisture);
  s_app.web_server_module().on("/api/status", HTTP_GET, apiGetStatus);
  s_app.web_server_module().onJson("/test/pump", HTTP_POST, pumpTest);

  for (int id = 1; id <= static_cast<int>(s_plants.size()); id++) {
    char path[80];
    snprintf(path, sizeof(path), "/api/plants/%d", id);
    s_app.web_server_module().onJson(
        path, HTTP_PUT,
        [id](og3::NetRequest* request, og3::NetResponse* response, JsonVariant& json) {
          return putApiPlant(id, request, response, json);
        });
  }

  s_app.web_server_module().onJson("/api/wifi", HTTP_PUT, putWifiConfig);
  s_app.web_server_module().onJson("/api/mqtt", HTTP_PUT, putMqttConfig);

  s_app.web_server_module().on("/api/restart", HTTP_POST,
                               [](og3::NetRequest* request, og3::NetResponse* response) {
                                 response->send(200, "text/plain", "restarting");
                                 s_app.tasks().runIn(1000, []() { ESP.restart(); });
                                 NET_REPLY(request, ESP_OK);
                               });

  s_app.setup();
}

void loop() { s_app.loop(); }

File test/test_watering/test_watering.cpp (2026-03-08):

// Copyright (c) 2026 Chris Lee and contributors.
// Licensed under the MIT license. See LICENSE file in the project root for details.

#include <ArduinoFake.h>
#include <cl3/logger.h>
#include <cl3/module.h>
#include <cl3/module_system.h>
#include <unity.h>
#include <watering.h>

#include <cstdio>
#include <string>
#include <vector>

namespace cl3 {

namespace {

class TestLogger : public Logger {
 public:
  virtual void log(const char* msg) final {
    m_output += msg;
    m_output += "\n";
  }
  bool check(const std::string& expected) {
    const bool ret = m_output == expected;
    if (!ret) {
      printf(
          "Expected '%s'\n"
          "but got  '%s'\n",
          expected.c_str(), m_output.c_str());
    }
    m_output.clear();
    return ret;
  }

 private:
  std::string m_output;
};

}  // namespace

}  // namespace cl3

void setUp() {}

void tearDown() {}

void test1() {
  cl3::TestLogger log;
  cl3::ModuleSystem depends(&log);
  og3::Tasks tasks(16, &depends);
  cl3::VariableGroup vg("test1");
  constexpr uint8_t kModeLED = 5;
  constexpr uint8_t kWaterPin = 6;
  constexpr uint8_t kPumpCtlPin = 7;

  using namespace fakeit;
  When(Method(ArduinoFake(), digitalWrite)).Return();
  When(Method(ArduinoFake(), millis)).Return(0, 10001, 20002, 30003, 40004);

  cl3::Watering watering(A0, kWaterPin, kModeLED, kPumpCtlPin, &tasks, &vg);

  Verify(Method(ArduinoFake(), millis)).Once();
  // Verify(Method(ArduinoFake(), digitalWrite)).Once();
  Verify(Method(ArduinoFake(), digitalWrite).Using(kPumpCtlPin, LOW)).Once();

  TEST_ASSERT_EQUAL_INT(cl3::Watering::kStateEval, watering.state());

  When(Method(ArduinoFake(), digitalRead)).Return(1);
  When(Method(ArduinoFake(), analogRead)).Return(730);       // low moisturef
  When(Method(ArduinoFake(), digitalWrite)).AlwaysReturn();  // pump off

  watering.loop();

  Verify(Method(ArduinoFake(), digitalRead)).Once();
  Verify(Method(ArduinoFake(), analogRead)).Once();
  // Verify(Method(ArduinoFake(), digitalWrite).Using(kPumpCtlPin, LOW)).Once();

  // TEST_ASSERT_EQUAL_INT(cl3::Watering::kStateWaitForNextCycle, watering.state());
}

int runUnityTests() {
  UNITY_BEGIN();
  RUN_TEST(test1);
  return UNITY_END();
}

// For native platform.
int main() { return runUnityTests(); }

// For arduion framework
void setup() {}
void loop() {}

// For ESP-IDF framework
void app_main() { runUnityTests(); }

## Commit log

2024-07-21 Initial content (#1)
    * initial version
    * Organize web pages by plant
    * Add project box and utilities
    * add readme
    * add copyright check
    * copyrights
    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
    [Plant1337.stl, Plant1337_test.scad, board.scad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]
2024-08-04 Deployment 1 (#2)
    - box: add screw-holes for box bottom, to attach to reservoir-hook
    - fix watering state names
    - ADC/moisture pins for latest PCB version
    - OLED: graphical display of moisture states
    - Configuration page for reservoir pump-secs after float goes low
    - Offset timing of state machines for different plants
    [box.scad, box_bottom.stl, box_top.stl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]
2024-08-04 box update (#3)
    * add hump for OLED screen
    * box: gui.py: button for launching OpenSCAD
    [box.scad, box_bottom.stl, box_top.stl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]
2024-09-19 Openscad & code updates (#6)
    - Move EBox to a `scad/box` subdirectory, and add number-labels for plant connectors.
    - Improve drawing of moisture level on OLED screen
    - Add OpenSCAD model of a soil-spike with holes for watering.
    - Added compile-check
    [Plant1337.stl, Plant1337_test.scad, board.scad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]
2024-09-19 Only use plant1 for LED-blink control. Version -> 0.7.1 (#7)
    * LED blinking only for plant0
    * update dependencies, version -> 0.7.1
2024-09-21 Comments, OpenSCAD sources, README updates (#8)
    * Improved comments in main.cpp
    * Added KiCAD project for the Plant1337 PCB
    * OpenSCAD models additions and fixes
    * reservoir insert
    * moisture sensor cap.
    * fixed Ebox
    * updated README
    [Plant1337.kicad_pcb, Plant1337.kicad_sch, box.scad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]
2024-09-21 add ebox (#9)
    [hook.scad, print_hook.scad, print_hook.stl]
2024-10-01 Update: watering library.json, ebox hook, reservoir insert (#10)
    - EBox hook: make top thicker for robustness
    - Rservoir insert: 4-pump version
    [gui.scad, hook.scad, insert_print.stl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]
2024-10-19 Make seconds between pump does configurable. (#16)
    Also:
    - version -> 0.7.2
    - move example .ini files into place before platformio test build in CI
2024-10-19 Limit number of pump doses in a watering cycle (#17)
    If there are too many pump doses in watering cycle, then switch to a
    "watering paused" state and wait for 12 hours.
    This is a safety features to avoid over-watering if something goes wrong,
    such as unreliable moisture sensor readings.
2024-10-20 Set AP password (#21)
    - If specified in secrets.ini, set a password on the soft-AP.
    - Also, switch mqtt client library to that used by ESPHome.
2024-10-24 update workflows (#24)
    * update workflows
    * added license headers
    [box.scad, box_bottom.scad, box_top.scad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]
2024-12-31 Ensure pump is off when not in a state which is explicitly watering. (#27)
2025-01-12 Update KiCAD model (#28)
2025-01-24 Fix limiting doses in 24 hours. (#29)
    - Fix limiting doses in 24 hours.
    - Use 64-bit clock values to avoid problems with value rollover.
    - Make end of watering-pause to be more consistent.
    - software version -> 0.8.0
    [main.cpp]
2025-08-01 Version 0.8.3 (#30)
    * Make a separate HA-discovery device for each plant
    * Updated year in copyright notices
    * HA discovery: set parent device for plants-devices
    * version -> 0.8.3
    * update copyright checker
    [Plant1337_test.scad, board.scad, box.scad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]
2025-10-19 Add svelte-based web interface (#31)
    - Add svelte-based web UI developed with the help of claude.
    - KiCAD update -> v1.3. Change pump2 DIO, remove pump pull-downs
    - board v1.3, test web page
    The old interface can still be reached by at the "/root" path.
    [Plant1337.kicad_pcb, Plant1337.kicad_sch, cl33mos.kicad_sch]
2025-11-02 Version update, board updates, stencil fixture (#32)
    * KiCad updates, OpenSCAD design for PCB-stencil holder
    * Added-back screw-holes at 2 corners of the board
    * og3 -> 0.3.96
    [Plant1337.kicad_pcb, stencil_fixture.scad, stencil_fixture.stl]
2025-11-28 Multiple improvements (#33)
    - Version -> 0.9.2
    - Updated version of KiCAD
    - OpenSCAD design for PCB/stencil holder
    - Added screw holes in corners of PCB
    - Updated Web interface (gemini)
    - Restart button
    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
2025-11-28 Use a watchdog timer for safety when pumping water (gemini) (#34)
2025-11-29 Disable watchdog timer during OTA firmware update (#35)
2026-02-01 Version 0.9.6: allow disabling MQTT (#39)
    This allows not publishing values while calibrating the moisture sensor.
2026-03-08 Use og3 for update web server, mqtt client (WIP) (#40)
    * license header util update
    * license header update
    * Gemini ported to og3 0.5.0 pre-release
    * updates for newer PsychicHttp
    * Re-organized platform.ini
    * CI: separate svelte build step is now redundant
    * Web interface updates
    Indicate whether:
    - Device is online/offline
    - Watering of each plant is enabled
    - Connected to MQTT broker
    * Only update filtered moisture sensor value if raw val is reasonable.
    * gemini updates for the CI build
    * setup local.ini when running CI
    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
    [Plant1337_test.scad, board.scad, box.scad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]
2026-10-25 Version 1.0.0 (#42)
    ### Added
    - **Hardware Board v2.x & ESP32-S3 Support**: Added PlatformIO configurations (`esp32s3`, `usb_s3`, `wifi_s3`), `BOARD_V20` pin mappings for `ESP32-S3-WROOM-1-N8R2` with USB-C, updated KiCAD schematics/PCB layouts (v2.0–v2.2 with boot/reset push-buttons and improved flyback diode placement), and BOM (`KiCAD/Plant133.csv`).
    - **3D-Printed Enclosure & Accessories**:
    - Updated EBox (`scad/box/`) for Board v2.1+ and added OLED support bracket (`OLEDSupport.scad`) and board test fixture (`fixture.scad`).
    - Added reservoir cover/cap (`scad/reservoir_cover/`) with cutouts for the EBox, tubing, and wires.
    - Updated reservoir insert (`scad/reservoir_insert/`) and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
